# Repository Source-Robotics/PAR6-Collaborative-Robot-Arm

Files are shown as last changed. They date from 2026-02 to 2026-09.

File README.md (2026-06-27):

> [!CAUTION]
> This is a BETA release: Instructions, code, and 3D print files may change in the future and are not yet finalized. If you want to be a part of beta testing check out **this [link!](https://docs.google.com/forms/d/e/1FAIpQLSfJVBVM5K6rCrFRtpijmTBLeePUdGDxUlWBni1VqBrAZwRCwg/viewform
)**

By building and using this system, you acknowledge that it is still under active development and may contain errors, incomplete features, or design issues. You are doing so entirely at your own risk and responsibility.

This project may require troubleshooting, modifications, and technical knowledge. Proceed only if you are comfortable working with electronics, mechanical systems, and software in a development-stage environment.
>

## 🐞 Beta Feedback & Support

Since this project is currently in beta, feedback is highly appreciated.

If you find any mistakes, bugs, or unclear parts, please report them, including issues in:

- Documentation
- BOM and assembly documentation
- Source code
- STL and other 3D print files

Please open an issue, send us a message on Discord, or contact us via email with as much detail as possible so we can fix it quickly.

## 🤝 Contributing

Use GitHub issues to track open work before starting a pull request:

- Open one issue per bug, task, or feature request.
- Keep each pull request focused on one logical change.
- Link the related issue in the pull request description.
- Describe what changed and what you tested.
- For larger changes, open an issue first and agree on the approach before coding.

 ### How you can contribute

Review issues: reproduce bugs reported by others, spot duplicates, improve descriptions, and help users who need support.
Submit fixes: pick an open issue or feature request and submit a pull request with your implementation.
Test pull requests: run proposed changes and report your results — testing on real hardware is invaluable.
Review contributions: help others by reviewing code and suggesting better implementation approaches.
Improve documentation: write new content or polish what's already there.

More details on how to contribute here: https://github.com/Source-Robotics/.github?tab=contributing-ov-file

## 🧩 Open TODOs

Open tasks that contributors can pick up. Before starting work, please open or comment on the related issue so work is not duplicated.

| Area | Task | Status |
| :--- | :--- | :---: |
| Documentation | Typos, readability changes, structure for the .md files| Open |
| Documentation | Finalize BOM,  Fix links, reference images, exact number of parts... | Open |
| Hardware | Create .3mf print files for robot (follow 3D printn table) | Open |
| Hardware | Issues in 3D print / model files. | Open |
| Hardware | Recommendations for easier assembly of the robot | Open |
| Software | TODO | Open |

Status options: `Open`, `In progress`, `Needs review`, `Blocked`, `Done`.

 ### How you can contribute

* Triage issues: reproduce bugs reported by others, spot duplicates, improve descriptions, and help users who need support.
* Submit fixes: pick an open issue or feature request and submit a pull request with your implementation.
* Test pull requests: run proposed changes and report your results — testing on real hardware is invaluable.
* Review contributions: help others by reviewing code and suggesting better implementation approaches.
* Improve documentation: write new content or polish what's already there.

## Related repos
* https://github.com/Source-Robotics/STEPFOC-stepper-controller
* https://github.com/Source-Robotics/RCB-Robot-Control-Box

<div align="center">

# PAR6-Collaborative-Robot-Arm

</div>

---

<p align="center">
  
  
  
  <a href="https://github.com/petercorke/robotics-toolbox-python">Powered by the Robotics Toolbox</a>
  
</p>

<p align="center">
  
  
  
  
  
  
</p>

<div align="center">

3D Printed Collaborative Robot - Open Source Software, Manuals & 3D print files ·

Designed for Embodied/Physical  AI, Safety & Ease of use

</div>

## 💡 News

[2025-04-03] Beta Release! Contributions from the open-source community are highly encouraged, and we welcome feedback and bug reports through the GitHub Issues page.

## 📖 Project Overview

PAR6 is a 3D-printed collaborative robot arm platform designed for research, education, and rapid prototyping in physical AI.

The project combines mechanical design files, assembly documentation, and software resources to support full-stack robotics development.

Key focus areas:

- Embodied AI and physical AI experiments and validation
- Teleoperation workflows and human-in-the-loop control
- Learning from demonstration (LfD) pipelines
- Imitation learning and dataset generation
- VLA-style data collection for AI-native robotics
- Accessible robotics research through open hardware and open documentation

## ⚒️How to build / Where to buy?

**Check video manuals below, Source all the parts from BOM**

**You will also need to build Control box from this repo:**
* https://github.com/Source-Robotics/RCB-Robot-Control-Box

## 📚Documentation:

| Resource | Description |
|---|---|
| [3D Print Files](3D%20Print%20Files/) | Printable STL part files for the PAR6 robot arm,  |
| [BOM](BOM/) | Bill of materials and reference images for sourcing the required parts |
| [Building Instructions](Building%20Instructions/) | Assembly notes, cable building instructions, and supporting datasheets -- **Check Video Manuals below**|
| [PAR6 Description](PAR6%20Description/) |  XML files, and URDF resources for simulation  |

Video Assembly manual
* https://youtu.be/3Rrd6hjBnM4

Cable Assembly:
* https://youtu.be/QlNfWAga1l0
* https://youtu.be/GOb1vQsjfOs

RCB Box:
* https://youtu.be/qAzd839ixuw

## ⚙️ Hardware Specifications

TODO

## 🌐 More about PAR6 robotic arm

| YouTube | Instagram | Twitter | LinkedIn |
|---|---|---|---|
|  |  |  |  |

| Discord | Forum | Hackaday | Blog |
|---|---|---| ---|
|  |  |  |  

## 🛡️ Licensing

**CERN Open Hardware Licence Version 2 - Strongly Reciprocal**

## 💸Support us

The majority of this project is open source and freely available to everyone. Your assistance, whether through donations or advice, is highly valued. Thank you!

 


## 🙌 References & Acknowledgments

## ⚠️ Safety, Liability & Disclaimer
This project includes experimental software, hardware designs, and assembly documentation that are still under development and may contain bugs, errors, or incomplete features. By using, building, or modifying this project, you acknowledge that:

* You use this project entirely at your own risk
* You are solely responsible for safe assembly, testing, and operation
* No guarantee is made regarding correctness, safety, or reliability
* The authors are not responsible for any damage, injury, or loss resulting from the use or misuse of this project
* Hardware performance and safety depend on user assembly, component quality, calibration, and handling, which cannot be guaranteed
* This project is provided “as is.” If you choose to build a device yourself using these files, designs, or instructions, you do so without any warranties or guarantees, including regarding safety, reliability, or suitability for any particular purpose.

THIS PROJECT INVOLVES LETHAL VOLTAGES AND OTHER SERIOUS HAZARDS THAT CAN CAUSE SEVERE INJURY. YOU MUST READ THE FULL [SAFETY WARNING AND DISCLAIMER DOCUMENT](SAFETY_WARNING_AND_DISCLAIMER.md)  BEFORE USING ANY PROJECT FILES. BY PROCEEDING, YOU ACKNOWLEDGE AND ACCEPT ALL RISKS AND AGREE TO USE THIS PROJECT ENTIRELY AT YOUR OWN RESPONSIBILITY.

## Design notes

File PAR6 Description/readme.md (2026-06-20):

# Source Robotics PAR6 Description (MJCF)

> [!IMPORTANT]
> Requires MuJoCo 3.1.3 or later.

## Changelog

See [CHANGELOG.md](./CHANGELOG.md) for a full history of changes.

## ⚒️TODO 

- Add correct joint limits to URDF and MJCF files

## Overview

This package contains a simplified robot description (MJCF) and URDF files of the [PAR6 robotic arm](https://source-robotics.com/) developed by [Source Robotics](https://source-robotics.com/).

There are 2 available MJCF files.

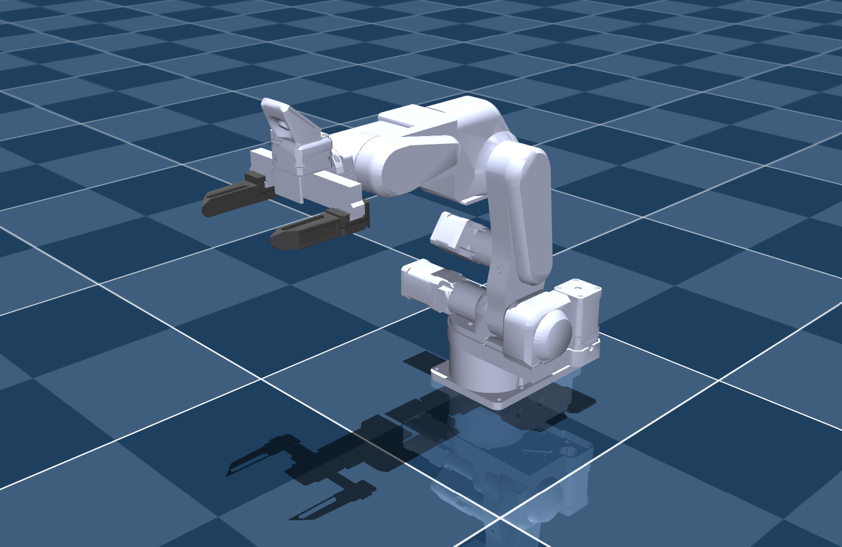
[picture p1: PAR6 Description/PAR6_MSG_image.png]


* PAR6 with MSG gripper

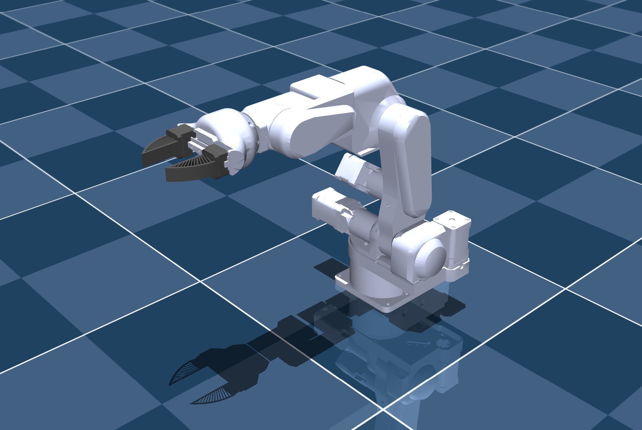
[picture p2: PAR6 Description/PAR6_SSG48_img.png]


* PAR6 with SSG48 gripper

## Online mujoco viewer

https://mujoco-viewer.org/

## URDF folder

[URDF](./URDF/) folder contains 3 different versions:
* PAR6 with flange
* PAR6 with MSG gripper
* PAR6 with SSG48 gripper

More about URDF here: [Link](./urdf.md)

## URDF → MJCF derivation steps

1. Loaded the URDF into MuJoCo and saved a corresponding MJCF.
2. Manually edited the MJCF to extract common properties into the `<default>` section.
3. Added position-controlled actuators for the arm.
4. Added `scene.xml` which includes the robot, with a textured groundplane, skybox, and haze.

## License

This model is released under an [Apache-2.0 License](LICENSE).

## References

Mjcf reference Mujoco managerie
- references: 
- https://mujoco.readthedocs.io/en/stable/XMLreference.html
- https://github.com/google-deepmind/mujoco_menagerie/tree/main/ufactory_lite6
- https://github.com/google-deepmind/mujoco_menagerie/blob/main/trossen_vx300s/vx300s.xml 
- https://github.com/google-deepmind/mujoco_menagerie/blob/main/aloha/aloha.xml
- https://github.com/google-deepmind/mujoco_menagerie/blob/main/franka_emika_panda/panda.xml 
- https://github.com/jeongeun980906/lerobot-mujoco-tutorial/blob/master/asset/robotis_omy/omy.xml

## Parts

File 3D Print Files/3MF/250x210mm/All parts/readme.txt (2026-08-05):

This file contains multiple plates with all the parts. In order to be correctly read, it might be necessary to open it using OrcaSlicer. It is for reference only, as there is both single color and multi colors folders available containing ready to print files.

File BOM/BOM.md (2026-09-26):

# PAR6 – Bill of Materials (BOM)

This BOM lists all components required to build the PAR6 robot arm based on the official kiting list.

> [!NOTE]
> If any product links are broken, unavailable, or no longer point to the correct item, please [open an issue](https://github.com/Source-Robotics/PAR6-Collaborative-Robot-Arm/issues/new), send us a message on Discord, or contact us via email. You can also use the reference images to find the same or an equivalent part from another supplier.

---

## RCB - Robot Control Box

The Robot Control Box is also required for the PAR6 build. Use the separate [RCB Robot Control Box BOM](https://github.com/Source-Robotics/RCB-Robot-Control-Box/blob/main/BOM/BOM.md) for the control box components.

---

## Screws and Nuts

| Diameter / Type | Length | Quantity | Description |
| :--- | :--- | :--- | :--- |
| M4 | 10 mm | 7 | DIN 912 / ISO 4762 (Socket head cap) 
| M3 | 8 mm | 50 | DIN 912 / ISO 4762 (Socket head cap) 
| M3 | 14 mm | 33 | DIN 912 / ISO 4762 (Socket head cap) 
| M3 | 25 mm | 4 | DIN 912 / ISO 4762 (Socket head cap) 
| M2 | 10 mm | 2 | DIN 912 / ISO 4762 (Socket head cap) 
| M2 | 4 mm | 2 | DIN 912 / ISO 4762 (Socket head cap) 
 M3 | 45 mm | 6 | DIN 912 / ISO 4762 (Socket head cap) 
  M3.5 | 14 mm | 8 | **used for shaft couplers!** DIN 912 / ISO 4762 (Socket head cap) 
| M3 | 16 mm | 6 | DIN 912 / ISO 4762 (Socket head cap) 
| M3 | 12 mm | 3 | DIN 912 / ISO 4762 (Socket head cap) 
| M4 | 16 mm | 16 | DIN 912 / ISO 4762 (Socket head cap) 
| M4 | 14 mm | 4 | DIN 912 / ISO 4762 (Socket head cap)
| M4 | 50 mm | 4 | DIN 912 / ISO 4762 (Socket head cap)
| M3 | 15 mm or 16 | 5 | Tapered / Countersunk screw head 
| M5 | 16 mm | 8 | DIN 912 / ISO 4762 (Socket head cap)|
| M3 | 22 mm | 4 | DIN 912 / ISO 4762 (Socket head cap)|
| M3 | 40 mm | 8 | DIN 912 / ISO 4762 (Socket head cap)| 
| M3| 60 mm | 12 | DIN 912 / ISO 4762 (Socket head cap)| 

---

---

## Consumables

| Name | Type | Quantity | Description | Link | 
| :--- | :--- | :--- | :--- | :--- |
| Threadlocker blue | Loctite 243 | 1 | Use for gearbox shaft coupler set screws|  | 
| Threadlocker green| Loctite 648 | 1 | Use for gearbox shaft couplers and shafts |  | 

---

## Gearboxes

> [!NOTE]
>     **Use EG series gearboxes for best perfromance. You can also mix EG and MG series as you wish for robots joints but for 1 robot you will need 1 x 10:1, 1 x 20:1 and 1 x 25:1 of any type either MG or EG**

| Name | Type | Quantity | Description | Link | ALT link| Reference Image |
| :--- | :--- | :--- | :--- | :--- | :--- |:--- |
| Gearbox 20:1 | Nema 17 20:1 | 1 | (Joint 3 gearbox - Elbow) EG Series precision planetary | [Link](https://www.omc-stepperonline.com/eg-series-planetary-gearbox-gear-ratio-20-1-backlash-20-arc-min-for-nema-17-stepper-motor-eg17-g20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) | [Alt Link](https://s.click.aliexpress.com/e/_oEhMNU5) | [Link](BOM%20reference%20images/stepper%2020_1.jpg) |
| Gearbox 10:1 | Nema 17 10:1 | 1 | (Joint 6 gearbox - Wrist 3) EG Series precision planetary | [Link](https://www.omc-stepperonline.com/eg-series-planetary-gearbox-gear-ratio-10-1-backlash-15-arc-min-for-nema-17-stepper-motor-eg17-g10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) | [Alt Link](https://s.click.aliexpress.com/e/_oEhMNU5) |[Link](BOM%20reference%20images/stepper%2010_1.jpg) |
| Gearbox 25:1 | Nema 17 25:1 | 1 | (Joint 1 gearbox - Shoulder) EG Series precision planetary | [Link](https://s.click.aliexpress.com/e/_c3b5S46t) | [Alt Link](https://s.click.aliexpress.com/e/_c2QcIBnD) |[Link](BOM%20reference%20images/stepper%2010_1.jpg) |

> [!NOTE]
>     **You can use Lower quality MSG type reducers. They offer a tradeoff where they are cheaper but have more backlash**

| Name | Type | Quantity | Description | Link | ALT link| Reference Image |
| :--- | :--- | :--- | :--- | :--- | :--- |:--- |
| Gearbox 20:1 | Nema 17 20:1 | 1 | (Joint 3 gearbox - Elbow) MGL Series precision planetary | [Link](https://www.omc-stepperonline.com/mgl-series-planetary-gearbox-gear-ratio-20-1-backlash-45arc-min-for-5mm-shaft-standard-nema-17-stepper-motor-mgl17-g20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) | [Alt Link](https://s.click.aliexpress.com/e/_c3JNRXad) | [Link](BOM%20reference%20images/stepper%2020_1.jpg) |
| Gearbox 10:1 | Nema 17 10:1 | 1 | (Joint 6 gearbox - Wrist 3) MGL Series precision planetary | [Link](https://www.omc-stepperonline.com/mgl-series-planetary-gearbox-gear-ratio-10-1-backlash-30arc-min-for-5mm-shaft-standard-nema-17-stepper-motor-mgl17-g10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) | [Alt Link](https://s.click.aliexpress.com/e/_c3JNRXad) |[Link](BOM%20reference%20images/stepper%2010_1.jpg) |
| Gearbox 25:1 | Nema 17 25:1 | 1 | (Joint 1 gearbox - Shoulder) MGL Series precision planetary | [Link](https://www.omc-stepperonline.com/mgl-series-planetary-gearbox-gear-ratio-25-1-backlash-45arc-min-for-5mm-shaft-standard-nema-17-stepper-motor-mgl17-g25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) | [Alt Link](https://s.click.aliexpress.com/e/_c3JNRXad) |[Link](BOM%20reference%20images/stepper%2010_1.jpg) |

---

## Motors

| Name | Type | Quantity | Description | Link | ALT link| Reference Image |
| :--- | :--- | :--- | :--- | :--- | :--- | :--- |
| Stepper 17HS08-1004S | Nema 17 | 1 | 16Ncm, 42x42x21.5mm; used in J6| [Link](https://www.omc-stepperonline.com/nema-17-bipolar-1-8deg-16ncm-22-6oz-in-1a-3-7v-42x42x20mm-4-wires-17hs08-1004s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) | [Alt Link](https://s.click.aliexpress.com/e/_oo1LTs7) |[Link](BOM%20reference%20images/stepper%2021_5mm.jpg) |
| Stepper 17HS16-2004S1 | Nema 17 | 2 | 45Ncm, 42x42x40mm; used in J5, J4| [Link](https://www.omc-stepperonline.com/nema-17-bipolar-45ncm-64oz-in-2a-42x42x40mm-4-wires-w-1m-cable-connector-17hs16-2004s1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) | [Alt Link](https://s.click.aliexpress.com/e/_oC1Ii0v) |[Link](BOM%20reference%20images/stepper%2040mm.jpg) |
| Stepper 17HS24-2104S | Nema 17 | 3 | 65Ncm, 42x42x60mm; used in J3, J2, J1 | [Link](https://www.omc-stepperonline.com/nema-17-bipolar-1-8deg-65ncm-92oz-in-2-1a-3-36v-42x42x60mm-4-wires-17hs24-2104s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) | [Alt Link](https://s.click.aliexpress.com/e/_opq2ugp) |[Link](BOM%20reference%20images/stepper%2060mm.jpg) |

---

## Belts and Pulleys

| Name | Type | Quantity | Description | Link | ALT link| Reference Image |
| :--- | :--- | :--- | :--- | :--- | :--- | :--- |
| Joint 1 belt | HTD3M 396 | 1 | 6 mm width | [Link](https://s.click.aliexpress.com/e/_c3LnffKl) | |[Link](BOM%20reference%20images/HTD%203M%20belt.png) |
| Joint 3 belt | HTD3M 342 | 1 | 6 mm width | [Link](https://s.click.aliexpress.com/e/_c4O7CHOd) | |[Link](BOM%20reference%20images/HTD%203M%20belt.png) |
| Joint 4 belt | HTD3M 201 | 1 | 6 mm width | [Link](https://s.click.aliexpress.com/e/_c4NiUycd) | |[Link](BOM%20reference%20images/HTD%203M%20belt.png) |
| Joint 5 belt | HTD3M 246 | 1 | 6 mm width | [Link](https://s.click.aliexpress.com/e/_c4DlcQaD) | |[Link](BOM%20reference%20images/HTD%203M%20belt.png) |
| J4/J5 Pulley | HTD3M 12T | 2 | 5mm bore, 10mm width | [Link](https://s.click.aliexpress.com/e/_DBVgkVp) | |[Link](BOM%20reference%20images/HTD%203M%20pulley.png) |
| J1 Pulley | HTD3M 15T | 1 | 5mm bore, 10mm width | [Link](https://s.click.aliexpress.com/e/_DBVgkVp) | |[Link](BOM%20reference%20images/HTD%203M%20pulley.png) |

---

## Shaft couplers

> [!NOTE]
>     **Joints 2 and 3 can use different shaft coupler options. Choose only one J2/J3 option below (quantity 2 total). Option 1 gives the best performance if you use the official shaft coupler or machine an equivalent part from the [custom and machined parts](Custom%20%26%20machined%20parts) files. Option 2 is a friction/tension based coupler. Option 3 uses the same coupler as the gripper/flange, but is more prone to slipping and requires the [alternative upper arm STL files](../3D%20Print%20Files/STL/A4_Upper_arm/Alternative%20files).**

| Option | Name | Type | Quantity | Description | Link | ALT link | Reference Image |
| :--- | :--- | :--- | :--- | :--- | :--- | :--- | :--- |
| Option 1 - Recommended Coming soon! | Shaft coupler | For J2 & J3 | 2 | Official or machined D8 oval flange coupler; best performance. See [custom and machined parts](Custom%20%26%20machined%20parts). | [Link](https://s.click.aliexpress.com/e/_c3UQtavB) | | [Link](BOM%20reference%20images/source_coupler.png) |
| Option 2 | Shaft coupler | For J2 & J3 | 2 | Friction/tension based D8 oval flange coupler; easier to source, but can slip more than Option 1 | [Link](https://s.click.aliexpress.com/e/_c3UQtavB) | | [Link](BOM%20reference%20images/D8_Oval_flange_coupler.png) |
| Option 3 | Shaft coupler | For J2 & J3 | 2 | Gripper/flange style coupler; most prone to slipping and requires the [alternative upper arm STL files](../3D%20Print%20Files/STL/A4_Upper_arm/Alternative%20files) | [Link](https://s.click.aliexpress.com/e/_c2xnQgI7) | | [Link](BOM%20reference%20images/shaft%20coupler%20gripper.png) |
| Required for grippers and flanges | Shaft coupler | For gripper / flange | 1 | M4 screw holes for the end flange or gripper | [Link](https://s.click.aliexpress.com/e/_c2xnQgI7) | | [Link](BOM%20reference%20images/shaft%20coupler%20gripper.png) |

## Bearings and Mechanical Components

| Name | Type | Quantity | Description | Link | ALT link| Reference Image |
| :--- | :--- | :--- | :--- | :--- | :--- | :--- |
| AXK3552 | AXK3552 needle bearing | 1 | 35X52X4, with plates | [Link](https://s.click.aliexpress.com/e/_Dk4bHg7) | |[Link](BOM%20reference%20images/AXK3552%20needle%20bearing.png) |
| NSK HR32906J| NSK HR32906J  Tapered bearing| 5 | Joint 5, 4 and 3 | [Link](https://s.click.aliexpress.com/e/_DcJMtBl) | |[Link](BOM%20reference%20images/Tapered%20bearing.png) |
| NSK HR32907J | NSK HR32907J Tapered bearing | 4 | Joint 1 and 2 | [Link](https://s.click.aliexpress.com/e/_DcJMtBl) | |[Link](BOM%20reference%20images/Tapered%20bearing.png) |
| Tensioning bearing | 3x8x4 | 2 | Ball bearing for belts | [Link](https://s.click.aliexpress.com/e/_DCjfgFV) | |[Link](BOM%20reference%20images/small%20tension%20bearings.png) |
| Tensioning bearing | 3x10x4 | 8 | Ball bearing for belts | [Link](https://s.click.aliexpress.com/e/_DlA33Af) | |[Link](BOM%20reference%20images/small%20tension%20bearings.png) |
 
## Mechanical Components

| Name | Type | Quantity | Description | Link | ALT link| Reference Image |
| :--- | :--- | :--- | :--- | :--- | :--- | :--- |
| Brass inserts |  | 6 | M3, 5mm len, 4.5 OD, used for Flange| [Link](https://s.click.aliexpress.com/e/_c2RX6lzp) | |[Link](BOM%20reference%20images/brass_insert.png) |

---

## PCBs

| Component | Type | Quantity | Description | Link | ALT link| Reference Image |
| :--- | :--- | :--- | :--- | :--- | :--- | :--- |
| Closed loop Stepper Drivers | STEPFOC | 6 | Stepper Drivers | [Link](https://source-robotics.com/products/stepfoc-stepper-controller) | |[Link](BOM%20reference%20images/STEPFOC%20stepper%20driver.png) |
| Gripper connector PCB |  | 1 | Source Robotics website only for beta for now | [Link](TODO) | |[Link](BOM%20reference%20images/Gripper%20connector%20PCB.jpg) |
| Hall sensor PCB |  | 1 | Source Robotics website only for beta for now | [Link](TODO) | |[Link](BOM%20reference%20images/Hall%20sensor%20PCB.jpg) |
| Base Distribution PCB |  | 1 |Source Robotics website only for beta for now | [Link](TODO) | |[Link](BOM%20reference%20images/Base%20Distribution%20board.jpg) |

## Electronics

| Component | Type | Quantity | Description | Link | ALT link| Reference Image |
| :--- | :--- | :--- | :--- | :--- | :--- | :--- |
| Motor controller Magnets | Diametrically Magnetised Magnets | 6 | Stepper Drivers encoder magnets | [Link](https://source-robotics.com/products/6x2-5mm-diametrical-neodymium-magnet) | |[Link](BOM%20reference%20images/Magnet.png) |
| Gripper Magnet | Axial Magnetised Magnets (Regular magnet) | 1 |  |  [Link](https://s.click.aliexpress.com/e/_c4tF3Rzf)  | |[Link](BOM%20reference%20images/Magnet.png) |
| Thermistor  | Thermistor NTC 100K 3950 | 6 | | [Link](https://source-robotics.com/products/100k-ntc-thermistor) | |[Link](BOM%20reference%20images/Thermistor.png) |
| Robot base connector | GX16 4PIN male connector | 1 | Male + Female pair (female part is used in cable making) | [Link](https://s.click.aliexpress.com/e/_c3o4afqR) | |[Link](BOM%20reference%20images/GX16.jpg) |
| E-stop | 19mm | 1 | Emergency switch | [Link](https://s.click.aliexpress.com/e/_c3TdMLgT) | |[Link](BOM%20reference%20images/19mm%20ESTOP.png) |
| Connectors JST ZH 1.5MM 2PIN male  |  | 10 | Used to make custom cables | [Link](https://s.click.aliexpress.com/e/_c37crJFp) | |[Link](BOM%20reference%20images/Connectors%20JST%20ZH.png) |
| Connectors JST XH 2.54MM 2PIN male |  | 10 | Used to make custom cables | [Link](https://s.click.aliexpress.com/e/_c2xeSW0J) | |[Link](BOM%20reference%20images/Connectors%20JST%20XH.jpg) |
| Thermal cement |  | 1 | Used to attach thermistor to stepper motor | [Link](https://s.click.aliexpress.com/e/_c3t5DkcN) | |[Link](BOM%20reference%20images/Thermal%20cement.jpg) |

---

## Wires / Cables

> [!IMPORTANT]
>     **If you dont want to build the wires yourself you can get the wire pack from our store (Coming soon)**

> [!NOTE]
>     **With wires make sure you follow [proper orientation](BOM%20reference%20images/ZH_XH_cable_direction.png) of the connector heads when ordering!**

| Name | Type | Quantity | Description | Link | ALT link| Reference Image |
| :--- | :--- | :--- | :--- | :--- | :--- | :--- |
| JST ZH 1.5MM 2PIN female-female 20-30cm |  | 3 | J5 motor - J6 motor, Gripper connector PCB - J4 wire, J4 motor - Extension wire J6,5,4  | [Link](https://s.click.aliexpress.com/e/_c4CyWKe1) | |[Link](BOM%20reference%20images/ZH_XH_cable_direction.png) |
| JST XH 2.54MM 2PIN female-female 20-30cm |  | 3| J5 motor - J6 motor, Gripper connector PCB - J4 wire, J4 motor - Extension wire J6,5,4  | [Link](https://s.click.aliexpress.com/e/_c4CyWKe1) | |[Link](BOM%20reference%20images/ZH_XH_cable_direction.png) |
| JST ZH 1.5MM 2PIN female-male 23cm | Extension wire (best to build your own)  | 2 | J5 motor - J6 motor,  J4 wire - J4 motor  | [Link]() | |[Link](BOM%20reference%20images/ZH_series_extension_cable.png) |
| JST XH 2.54MM 2PIN female-male 23cm | Extension wire (best to build your own)  |2 | J5 motor - J6 motor,  J4 wire - J4 motor  | [Link]() | |[Link](BOM%20reference%20images/XH_series_extension_cable.png) |
| JST ZH 1.5MM 2PIN female-female 10cm |  | 1 | J5 motor - Gripper connector PCB  | [Link](https://s.click.aliexpress.com/e/_c4CyWKe1) | |[Link](BOM%20reference%20images/ZH_XH_cable_direction.png) |
| JST XH 2.54MM 2PIN female-female 10cm |  |1 | J5 motor - Gripper connector PCB  | [Link](https://s.click.aliexpress.com/e/_c4CyWKe1) | |[Link](BOM%20reference%20images/ZH_XH_cable_direction.png) |
| JST ZH 1.5MM 2PIN male-bare wire 50cm | Best to build your own by extending the linked wires | 1 | Extension wire J6,5,4 -  Base Distribution PCB | [Link](https://s.click.aliexpress.com/e/_c4CyWKe1) | |[Link](BOM%20reference%20images/barewire4.png) | 
| JST XH 2.54MM 2PIN male-bare wire 50cm | Best to build your own by extending the linked wires | 1| Extension wire J6,5,4 -  Base Distribution PCB  | [Link](https://s.click.aliexpress.com/e/_c4CyWKe1) | |[Link](BOM%20reference%20images/barewire1.png) |
| JST ZH 1.5MM 2PIN female-bare wire 50cm | Best to build your own by extending the linked wires | 3 | J3 motor -  Base Distribution PCB, J2 motor -  Base Distribution PCB, J1 motor -  Base Distribution PCB| [Link](https://s.click.aliexpress.com/e/_c4CyWKe1) | |[Link](BOM%20reference%20images/barewire3.png) |
| JST XH 2.54MM 2PIN female-bare wire 50cm |Best to build your own by extending the linked wires  | 3| J3 motor -  Base Distribution PCB, J2 motor -  Base Distribution PCB, J1 motor -  Base Distribution PCB | [Link](https://s.click.aliexpress.com/e/_c4CyWKe1) | |[Link](BOM%20reference%20images/barewire2.png) |
| 18AWG wire 4 colors |  4 wires of 10cm|  |  GX16 connector -  Base Distribution PCB | [Link](https://s.click.aliexpress.com/e/_c3gZPIyV) | |[Link]() |
| Thin wire 3 colors 20 cm AWG 30 - 35|  | | Hall sensor PCB - J6 motor  | [Link](https://s.click.aliexpress.com/e/_c2v3zfdb) | |[Link]() |
| Wire 2 colors for XH extensions | 22 or 24 AWG | 5m black + 5m red | Extending XH power cables and building the bare wire cables above | | | |
| Wire 2 colors for ZH extensions | 28 AWG | 5m black + 5m red | Extending ZH CAN cables and building the bare wire cables above | | | |

---

> [!IMPORTANT]
>     **Cable building guide is [here](../Assembly%20manual/Building_cables.md)**

> [!IMPORTANT]
>     **If you dont want to build the cables yourself you can get the cable pack from our store (Coming soon)**

---

## Electric Gripper options

Default end effector is basic flange. That part can be used to attach any other custom grippers.

Officially supported open-source grippers are:

| Name | Type | Link to buy | Link to build |
| :--- | :--- | :--- | :--- |
MSG compliant AI gripper | Electric - CAN bus comms|  [Link](https://source-robotics.com/products/msg-gripper)  | [Link](https://github.com/Source-Robotics/MSG-compliant-AI-stepper-gripper)  |
SSG48 compliant gripper | Electric - CAN bus comms|  [Link](https://source-robotics.com/products/compliant-gripper) | [Link](https://github.com/Source-Robotics/SSG-48-adaptive-electric-gripper)  |

> [!NOTE]
>     **MSG gripper come in different grip and torque sizes!**

---

## MSG & SSG48 gripper cable

Buy Official cables from Source Robotics: [Link](TODO)

Parts needed if DIY your own cable:

| Type | Length / Spec | Quantity | Description | Link |
|---|---|---|---|---|
| 26 AWG cable | 0.15 mm², 4-wire twisted pair | 0.4 m | ~40 cm usually sufficient | [Link](https://s.click.aliexpress.com/e/_c4m3ggwn) |
| M8 4-pin male wire connector | — | 1 | [See reference image](../BOM/BOM%20reference%20images/M8%20male.png) |[Link](https://s.click.aliexpress.com/e/_c4OWHPKF) |
| M8 4-pin female wire connector | — | 1 | [See reference image](../BOM/BOM%20reference%20images/M8_female.png) | [Link](https://s.click.aliexpress.com/e/_c4OWHPKF) |

> [!NOTE]
>     **PAROL6 and PAR6 use different cables for SSG48 and MSG grippers. Using incorrect one can damage your robot**

## Pneumatics (optional)

> [!NOTE]
>     **These are the items we recommend if you are going to use Pneumatics with PAR6.**

| Name | Type | Quantity | Description | Link | ALT link| Reference Image |
| :--- | :--- | :--- | :--- | :--- | :--- | :--- |
| MHZ2-16D gripper | 4mm PM | 1 | Robot side connector | [Link](https://s.click.aliexpress.com/e/_DD83OLZ) |
| Pneumatic Tube |  | 4x2.5mm | Polyurethane tube | [Link](https://s.click.aliexpress.com/e/_DEhvFyJ) |
| Solenoid valve | 4mm tube connectors, 5/2, 24V | 1 | Polyurethane tube | [Link](https://s.click.aliexpress.com/e/_DDrw0Ux) |

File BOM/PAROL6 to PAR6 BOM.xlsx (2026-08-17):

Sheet: Comparison
PAROL6 vs PAR6 (arm + RCB) - part by part
PAROL6 quantities are as listed in its BOM (screws, bearings and similar are pack sizes). PAR6 quantities are arm + RCB needs combined; rows marked (RCB) are control box parts.
Part | PAROL6 qty | PAR6 qty | Status | Note
MOTORS

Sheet: PAROL6 BOM
PAROL6 - Bill of Materials
Source, fetched 2026-08-17: | https://github.com/PCrnjak/PAROL6-Desktop-robot-arm/blob/main/BOM/BOM.md
Screws and Nuts
Diameter / Type | Length | Quantity | Description
M4 | 10 mm | 20 | DIN 912 / ISO 4762 (hexagon socket head cap)
M3 | 8 mm | 10 | 2 mm head height
M3 | 8 mm | 50 | DIN 912 / ISO 4762 (hexagon socket head cap)
M3 | 14 mm | 30 | DIN 912 / ISO 4762 (hexagon socket head cap)
M3 nut | - | 10 | DIN 912 / ISO 4762 (hexagon socket head cap)
M3 | 25 mm | 10 | DIN 912 / ISO 4762 (hexagon socket head cap)
M2 | 10 mm | 10 | DIN 912 / ISO 4762 (hexagon socket head cap)
M3 | 16 mm | 10 | DIN 912 / ISO 4762 (hexagon socket head cap)
M3 | 6 mm | 10 | Pan head phillips
M3 | 12 mm | 30 | DIN 912 / ISO 4762 (hexagon socket head cap)
M3 | 35 mm | 10 | DIN 912 / ISO 4762 (hexagon socket head cap)
M4 | 16 mm | 30 | DIN 912 / ISO 4762 (hexagon socket head cap)
M4 | 14 mm | 10 | DIN 912 / ISO 4762 (hexagon socket head cap)
M4 | 50 mm | 10 | DIN 912 / ISO 4762 (hexagon socket head cap)
M3 | 15 mm | 2 | Tapered screw head
Gearboxes
For cheaper gearbox options you can use MG series planetary gearboxes. They have bigger backlash but are cheaper. Link - Aliexpress Link (https://www.omc-stepperonline.com/mg-series-planetary-gearbox)
Name | Type | Quantity | Description | Link | ALT link | Reference Image
Gearbox 20:1 | Nema 17 20:1 | 2 | EG precision planetary | Link (https://www.omc-stepperonline.com/eg-series-planetary-gearbox-gear-ratio-20-1-backlash-20-arc-min-for-nema-17-stepper-motor-eg17-g20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) | Link (https://s.click.aliexpress.com/e/_oEhMNU5) | Link (https://github.com/PCrnjak/PAROL6-Desktop-robot-arm/blob/main/BOM/BOM%20reference%20images/stepper%2020_1.jpg)
Gearbox 10:1 | Nema 17 10:1 | 1 | EG precision planetary | Link (https://www.omc-stepperonline.com/eg-series-planetary-gearbox-gear-ratio-10-1-backlash-15-arc-min-for-nema-17-stepper-motor-eg17-g10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) | Link (https://s.click.aliexpress.com/e/_oEhMNU5) | Link (https://github.com/PCrnjak/PAROL6-Desktop-robot-arm/blob/main/BOM/BOM%20reference%20images/stepper%2010_1.jpg)
Motors
Name | Type | Quantity | Description | Link | ALT link | Reference Image
Stepper 1 | Nema 17 | 1 | 16Ncm, 42x42x20mm | Link (https://www.omc-stepperonline.com/nema-17-bipolar-1-8deg-16ncm-22-6oz-in-1a-3-7v-42x42x20mm-4-wires-17hs08-1004s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) | Link (https://s.click.aliexpress.com/e/_oo1LTs7) | Link (https://github.com/PCrnjak/PAROL6-Desktop-robot-arm/blob/main/BOM/BOM%20reference%20images/stepper%2021_5mm.jpg)
Stepper 2 | Nema 17 | 3 | 45Ncm, 42x42x40mm | Link (https://www.omc-stepperonline.com/nema-17-bipolar-45ncm-64oz-in-2a-42x42x40mm-4-wires-w-1m-cable-connector-17hs16-2004s1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) | Link (https://s.click.aliexpress.com/e/_oC1Ii0v) | Link (https://github.com/PCrnjak/PAROL6-Desktop-robot-arm/blob/main/BOM/BOM%20reference%20images/stepper%2040mm.jpg)
Stepper 3 | Nema 17 | 2 | 65Ncm, 42x42x60mm | Link (https://www.omc-stepperonline.com/nema-17-bipolar-1-8deg-65ncm-92oz-in-2-1a-3-36v-42x42x60mm-4-wires-17hs24-2104s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) | Link (https://s.click.aliexpress.com/e/_opq2ugp) | Link (https://github.com/PCrnjak/PAROL6-Desktop-robot-arm/blob/main/BOM/BOM%20reference%20images/stepper%2060mm.jpg)
Belts
Name | Type | Quantity | Description | Link | ALT link | Reference Image
Joint 1 belt | HTD3 396 | 1 | 6 mm width | Link (https://s.click.aliexpress.com/e/_c3LnffKl) |  | Link (https://github.com/PCrnjak/PAROL6-Desktop-robot-arm/blob/main/BOM/BOM%20reference%20images/HTD%203M%20belt.png)
Joint 3 belt | HTD3 342 | 1 | 6 mm width | Link (https://s.click.aliexpress.com/e/_c4O7CHOd) |  | Link (https://github.com/PCrnjak/PAROL6-Desktop-robot-arm/blob/main/BOM/BOM%20reference%20images/HTD%203M%20belt.png)
Joint 4 belt | HTD3 201 | 1 | 6 mm width | Link (https://s.click.aliexpress.com/e/_c4NiUycd) |  | Link (https://github.com/PCrnjak/PAROL6-Desktop-robot-arm/blob/main/BOM/BOM%20reference%20images/HTD%203M%20belt.png)
Joint 5 belt | HTD3 246 | 1 | 6 mm width | Link (https://s.click.aliexpress.com/e/_c4DlcQaD) |  | Link (https://github.com/PCrnjak/PAROL6-Desktop-robot-arm/blob/main/BOM/BOM%20reference%20images/HTD%203M%20belt.png)
Pulleys
Name | Type | Quantity | Description | Link | ALT link | Reference Image
J4 pulley, J5 pulley | HTD3M 12 tooth | 2 | 5mm bore, 10mm width | Link (https://s.click.aliexpress.com/e/_DFYERWX) |  | Link (https://github.com/PCrnjak/PAROL6-Desktop-robot-arm/blob/main/BOM/BOM%20reference%20images/HTD%203M%20pulley.png)
J1 pulley | HTD3M 15 tooth | 1 | 5mm bore, 10mm width | Link (https://s.click.aliexpress.com/e/_DBVgkVp) |  | Link (https://github.com/PCrnjak/PAROL6-Desktop-robot-arm/blob/main/BOM/BOM%20reference%20images/HTD%203M%20pulley.png)
Shaft couplers
Name | Type | Quantity | Description | Link | ALT link | Reference Image
Shaft coupler | Shaft coupler | 3 | 8 mm hole shaft, M4 screw holes | Link (https://s.click.aliexpress.com/e/_c2xnQgI7) |  | Link (https://github.com/PCrnjak/PAROL6-Desktop-robot-arm/blob/main/BOM/BOM%20reference%20images/shaft%20coupler%20gripper.png)
Bearings
Name | Type | Quantity | Description | Link | ALT link | Reference Image
Bearing 1 | AXK3552 | 1 | 35X52X4, needs to have top and bottom plate | Link (https://s.click.aliexpress.com/e/_Dk4bHg7) |  | Link (https://github.com/PCrnjak/PAROL6-Desktop-robot-arm/blob/main/BOM/BOM%20reference%20images/AXK3552%20needle%20bearing.png)
Bearing 2 | NSK HR32906J | 5 | Joint 5, 4 and 3 | Link (https://s.click.aliexpress.com/e/_DcJMtBl) |  | Link (https://github.com/PCrnjak/PAROL6-Desktop-robot-arm/blob/main/BOM/BOM%20reference%20images/Tapered%20bearing.png)
Bearing 3 | NSK HR32907J | 4 | Joint 1 and 2 | Link (https://s.click.aliexpress.com/e/_DcJMtBl) |  | Link (https://github.com/PCrnjak/PAROL6-Desktop-robot-arm/blob/main/BOM/BOM%20reference%20images/Tapered%20bearing.png)
Tension bearing | Ball bearing 3x8x4 | 20 | Used for belt tension | Link (https://s.click.aliexpress.com/e/_DCjfgFV) |  | Link (https://github.com/PCrnjak/PAROL6-Desktop-robot-arm/blob/main/BOM/BOM%20reference%20images/small%20tension%20bearings.png)
Tension bearing | Ball bearing 3x10x4 | 20 | Used for belt tension | Link (https://s.click.aliexpress.com/e/_DlA33Af) |  | Link (https://github.com/PCrnjak/PAROL6-Desktop-robot-arm/blob/main/BOM/BOM%20reference%20images/small%20tension%20bearings.png)
Electronics
Name | Type | Quantity | Description | Link | ALT link | Reference Image
PAROL control board |  | 1 | source-robotics.com | Link (https://source-robotics.com/products/parol6-control-board)
TMC5160 |  | 6 | Drivers from the links are tested. Use any other at own risk | Link (https://s.click.aliexpress.com/e/_c3Jc52V9) | Link (https://s.click.aliexpress.com/e/_Dd8Cjkb)
Thermal paste / cement |  | 2 | Needed only if your control board has no drivers! | Link (https://s.click.aliexpress.com/e/_c2u86OEn) |  | Link (https://github.com/PCrnjak/PAROL6-Desktop-robot-arm/blob/main/BOM/BOM%20reference%20images/Thermal%20cement.jpg)
On/Off button |  | 1 | 12mm 3-6V | Link (https://s.click.aliexpress.com/e/_DBpZV3h) |  | Link (https://github.com/PCrnjak/PAROL6-Desktop-robot-arm/blob/main/BOM/BOM%20reference%20images/button.png)
JST PH 2.0mm 200mm 4PIN |  | 1 | For power button | Link (https://s.click.aliexpress.com/e/_DeObQ1D) |  | Link (https://github.com/PCrnjak/PAROL6-Desktop-robot-arm/blob/main/BOM/BOM%20reference%20images/JST_PH.png)
Noctua NF-A4x20 5V 40mm |  | 1 | or any 40mm 5V fan
Power connector - male + female |  | 1 | GX16 2PIN | Link (https://s.click.aliexpress.com/e/_DcHjMfN) |  | Link (https://github.com/PCrnjak/PAROL6-Desktop-robot-arm/blob/main/BOM/BOM%20reference%20images/GX16.jpg)
Gripper connector (electric) |  | 1 | M8 sensor Female 4 pin | Link (https://s.click.aliexpress.com/e/_DDQz9iP) |  | Link (https://github.com/PCrnjak/PAROL6-Desktop-robot-arm/blob/main/BOM/BOM%20reference%20images/M8%20connector%20female%204pin.png)
Power supply |  | 1 | Any 24V 5A supply | Link (https://www.omc-stepperonline.com/edr-120-24-mean-well-120w-24vdc-5a-115-230vac-din-rail-power-supply-edr-120-24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) | Link (https://s.click.aliexpress.com/e/_olFOM5Z)
Limit switches |  | 3 | Type ZW12-3 | Link (https://s.click.aliexpress.com/e/_DBq6eeF) |  | Link (https://github.com/PCrnjak/PAROL6-Desktop-robot-arm/blob/main/BOM/BOM%20reference%20images/LIMIT_SWITCH.png)
Inductive sensor 1 |  | 1 | 4mm NPN NO | Link (https://s.click.aliexpress.com/e/_c40MRkk5) | Link (https://s.click.aliexpress.com/e/_c3CMbO1h) | Link (https://github.com/PCrnjak/PAROL6-Desktop-robot-arm/blob/main/BOM/BOM%20reference%20images/INDUCTIVE_4MM.png)
Inductive sensor 2 |  | 1 | GX-F8A | Link (https://s.click.aliexpress.com/e/_c4VxLtW3) |  | Link (https://github.com/PCrnjak/PAROL6-Desktop-robot-arm/blob/main/BOM/BOM%20reference%20images/GX-F8A.png)
Inductive sensor 3 |  | 1 | M5, NPN NO | Link (https://s.click.aliexpress.com/e/_c3zGvxrP) | Link (https://s.click.aliexpress.com/e/_c3CMbO1h) | Link (https://github.com/PCrnjak/PAROL6-Desktop-robot-arm/blob/main/BOM/BOM%20reference%20images/INDUCTIVE_5MM.png)
Estop |  | 1 | Any NC estop | Link (https://s.click.aliexpress.com/e/_c3Bn4RR5) |  | Link (https://github.com/PCrnjak/PAROL6-Desktop-robot-arm/blob/main/BOM/BOM%20reference%20images/19mm%20ESTOP.png)
Cable gland for estop |  | 1 | PG7 type | Link (https://s.click.aliexpress.com/e/_DdJj62p) |  | Link (https://github.com/PCrnjak/PAROL6-Desktop-robot-arm/blob/main/BOM/BOM%20reference%20images/CABLE_GLAND.png)
M3 brass insert |  | 4 | M3, 6mm lenght | Link (https://s.click.aliexpress.com/e/_DmZR9AN) |  | Link (https://github.com/PCrnjak/PAROL6-Desktop-robot-arm/blob/main/BOM/BOM%20reference%20images/brass_insert.png)
Pneumatic connector - robot |  | 4 | 4 mm type PM | Link (https://s.click.aliexpress.com/e/_c3GpN5cR) |  | Link (https://github.com/PCrnjak/PAROL6-Desktop-robot-arm/blob/main/BOM/BOM%20reference%20images/PM4.png)
Pneumatic Gripper |  | 1 | MHZ2-16D | Link (https://s.click.aliexpress.com/e/_c4EJl0Qr) |  | Link (https://github.com/PCrnjak/PAROL6-Desktop-robot-arm/blob/main/BOM/BOM%20reference%20images/MHZ.png)
Pneumatic gripper connector |  | 2 | PC4 - M5 | Link (https://s.click.aliexpress.com/e/_DkCJqUL) |  | Link (https://github.com/PCrnjak/PAROL6-Desktop-robot-arm/blob/main/BOM/BOM%20reference%20images/PC4-M5.png)
Pneumatic tube |  | 5 meters | 1 meter, 4x2.5mm | Link (https://s.click.aliexpress.com/e/_DEhvFyJ) |  | Link (https://github.com/PCrnjak/PAROL6-Desktop-robot-arm/blob/main/BOM/BOM%20reference%20images/Pneumatic_tube.png)
xt30 connector female |  | 1 | Used to deliver power to PAROL6 PCB | Link (https://s.click.aliexpress.com/e/_DllR7eL)
Stlink / programming adapter |  | 1 | Use our Official programming adapter for ease of use! Pin order needs to be: SWCLK, SWDIO, GND, 3V3, 5V (https://source-robotics.com/products/parol6-programming-adapter) | Link (https://s.click.aliexpress.com/e/_DCPwBnn)
USB B cable |  | 1 | Comms to the PC
5/2 solenoid air valve |  | 1 | 4mm tube connectors, 5/2, 24V | Link (https://s.click.aliexpress.com/e/_DDrw0Ux) |  | Link (https://github.com/PCrnjak/PAROL6-Desktop-robot-arm/blob/main/BOM/BOM%20reference%20images/solenoid_valve.png)
Vacuum gripper
Name | Type | Quantity | Description | Link | ALT link | Reference Image
Suction cup gripper |  | 1 |  | Link (https://www.aliexpress.com/item/4000538850003.html)
Vacuum generator |  | 1 |  | Link (https://s.click.aliexpress.com/e/_DdTAyOZ)
4mm to 6mm coupler |  | 1 |  | Link (https://s.click.aliexpress.com/e/_DeEEqHR)
Small print bed modification
These parts are only needed if your printer bed is too small for `J1_turret_rework_blocker` and `Upper_arm`. Both parts are split in two and joined with dowel pins and epoxy after printing. STL files are in STL/SMALL_PRINT_BED. Nothing else in the build changes. (https://github.com/PCrnjak/PAROL6-Desktop-robot-arm/blob/main/BOM/../STL/SMALL_PRINT_BED)
Name | Type | Quantity | Description | Link | ALT link | Reference Image
J1 turret dowel pin | Dowel pin 4 x 18 mm | 3 | Solid cylindrical, stainless or hardened steel | Link (https://www.aliexpress.com/item/1005009401701158.html)
Upper arm dowel pin | Dowel pin 6 x 22 mm | 4 | Solid cylindrical, stainless or hardened steel | Link (https://www.aliexpress.com/item/1005009401701158.html)
Two part epoxy | Epoxy adhesive | 1 | 1:1 mix, slow setting | Link (https://www.aliexpress.com/item/1005012397836514.html)

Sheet: PAR6 Arm BOM
PAR6 arm - Bill of Materials
Source, fetched 2026-08-17: | https://github.com/Source-Robotics/PAR6-Collaborative-Robot-Arm/blob/main/BOM/BOM.md
The RCB Robot Control Box is also required for the PAR6 build. See the RCB BOM sheet.
Screws and Nuts
Diameter / Type | Length | Quantity | Description
M4 | 10 mm | 7 | DIN 912 / ISO 4762 (Socket head cap)
M3 | 8 mm | 50 | DIN 912 / ISO 4762 (Socket head cap)
M3 | 14 mm | 33 | DIN 912 / ISO 4762 (Socket head cap)
M3 | 25 mm | 4 | DIN 912 / ISO 4762 (Socket head cap)
M2 | 10 mm | 2 | DIN 912 / ISO 4762 (Socket head cap)
M2 | 4 mm | 2 | DIN 912 / ISO 4762 (Socket head cap)
M3 | 16 mm | 6 | DIN 912 / ISO 4762 (Socket head cap)
M3 | 12 mm | 3 | DIN 912 / ISO 4762 (Socket head cap)
M4 | 16 mm | 16 | DIN 912 / ISO 4762 (Socket head cap)
M4 | 14 mm | 4 | DIN 912 / ISO 4762 (Socket head cap)
M4 | 50 mm | 4 | DIN 912 / ISO 4762 (Socket head cap)
M3 | 15 mm or 16 | 5 | Tapered / Countersunk screw head
M5 | 16 mm | 8 | DIN 912 / ISO 4762 (Socket head cap)
M3 | 22 mm | 4 | DIN 912 / ISO 4762 (Socket head cap)
M3 | 40 mm | 8 | DIN 912 / ISO 4762 (Socket head cap)
M3 | 60 mm | 12 | DIN 912 / ISO 4762 (Socket head cap)
Consumables
Name | Type | Quantity | Description | Link
Threadlocker blue | Loctite 243 | 1 | Use for gearbox shaft coupler set screws
Threadlocker green | Loctite 648 | 1 | Use for gearbox shaft couplers and shafts
Gearboxes
**Use EG series gearboxes for best perfromance. You can also mix EG and MG series as you wish for robots joints but for 1 robot you will need 1 x 10:1, 1 x 20:1 and 1 x 25:1 of any type either MG or EG**
**You can use Lower quality MSG type reducers. They offer a tradeoff where they are cheaper but have more backlash**
Name | Type | Quantity | Description | Link | ALT link | Reference Image
Gearbox 20:1 | Nema 17 20:1 | 1 | EG Series precision planetary | Link (https://www.omc-stepperonline.com/eg-series-planetary-gearbox-gear-ratio-20-1-backlash-20-arc-min-for-nema-17-stepper-motor-eg17-g20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) | Link (https://s.click.aliexpress.com/e/_oEhMNU5) | Link (https://github.com/Source-Robotics/PAR6-Collaborative-Robot-Arm/blob/main/BOM/BOM%20reference%20images/stepper%2020_1.jpg)
Gearbox 10:1 | Nema 17 10:1 | 1 | EG Series precision planetary | Link (https://www.omc-stepperonline.com/eg-series-planetary-gearbox-gear-ratio-10-1-backlash-15-arc-min-for-nema-17-stepper-motor-eg17-g10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) | Link (https://s.click.aliexpress.com/e/_oEhMNU5) | Link (https://github.com/Source-Robotics/PAR6-Collaborative-Robot-Arm/blob/main/BOM/BOM%20reference%20images/stepper%2010_1.jpg)
Gearbox 25:1 | Nema 17 25:1 | 1 | EG Series precision planetary | Link (https://s.click.aliexpress.com/e/_c3b5S46t) | Link (https://s.click.aliexpress.com/e/_c2QcIBnD) | Link (https://github.com/Source-Robotics/PAR6-Collaborative-Robot-Arm/blob/main/BOM/BOM%20reference%20images/stepper%2010_1.jpg)
Name | Type | Quantity | Description | Link | ALT link | Reference Image
Gearbox 20:1 | Nema 17 20:1 | 1 | MGL Series precision planetary | Link (https://www.omc-stepperonline.com/mgl-series-planetary-gearbox-gear-ratio-20-1-backlash-45arc-min-for-5mm-shaft-standard-nema-17-stepper-motor-mgl17-g20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) | Link (https://s.click.aliexpress.com/e/_c3JNRXad) | Link (https://github.com/Source-Robotics/PAR6-Collaborative-Robot-Arm/blob/main/BOM/BOM%20reference%20images/stepper%2020_1.jpg)
Gearbox 10:1 | Nema 17 10:1 | 1 | MGL Series precision planetary | Link (https://www.omc-stepperonline.com/mgl-series-planetary-gearbox-gear-ratio-10-1-backlash-30arc-min-for-5mm-shaft-standard-nema-17-stepper-motor-mgl17-g10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) | Link (https://s.click.aliexpress.com/e/_c3JNRXad) | Link (https://github.com/Source-Robotics/PAR6-Collaborative-Robot-Arm/blob/main/BOM/BOM%20reference%20images/stepper%2010_1.jpg)
Gearbox 25:1 | Nema 17 25:1 | 1 | MGL Series precision planetary | Link (https://www.omc-stepperonline.com/mgl-series-planetary-gearbox-gear-ratio-25-1-backlash-45arc-min-for-5mm-shaft-standard-nema-17-stepper-motor-mgl17-g25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) | Link (https://s.click.aliexpress.com/e/_c3JNRXad) | Link (https://github.com/Source-Robotics/PAR6-Collaborative-Robot-Arm/blob/main/BOM/BOM%20reference%20images/stepper%2010_1.jpg)
Motors
Name | Type | Quantity | Description | Link | ALT link | Reference Image
Stepper 17HS08-1004S | Nema 17 | 1 | 16Ncm, 42x42x21.5mm; used in J6 | Link (https://www.omc-stepperonline.com/nema-17-bipolar-1-8deg-16ncm-22-6oz-in-1a-3-7v-42x42x20mm-4-wires-17hs08-1004s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) | Link (https://s.click.aliexpress.com/e/_oo1LTs7) | Link (https://github.com/Source-Robotics/PAR6-Collaborative-Robot-Arm/blob/main/BOM/BOM%20reference%20images/stepper%2021_5mm.jpg)
Stepper 17HS16-2004S1 | Nema 17 | 2 | 45Ncm, 42x42x40mm; used in J5, J4 | Link (https://www.omc-stepperonline.com/nema-17-bipolar-45ncm-64oz-in-2a-42x42x40mm-4-wires-w-1m-cable-connector-17hs16-2004s1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) | Link (https://s.click.aliexpress.com/e/_oC1Ii0v) | Link (https://github.com/Source-Robotics/PAR6-Collaborative-Robot-Arm/blob/main/BOM/BOM%20reference%20images/stepper%2040mm.jpg)
Stepper 17HS24-2104S | Nema 17 | 3 | 65Ncm, 42x42x60mm; used in J3, J2, J1 | Link (https://www.omc-stepperonline.com/nema-17-bipolar-1-8deg-65ncm-92oz-in-2-1a-3-36v-42x42x60mm-4-wires-17hs24-2104s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) | Link (https://s.click.aliexpress.com/e/_opq2ugp) | Link (https://github.com/Source-Robotics/PAR6-Collaborative-Robot-Arm/blob/main/BOM/BOM%20reference%20images/stepper%2060mm.jpg)
Belts and Pulleys
Name | Type | Quantity | Description | Link | ALT link | Reference Image
Joint 1 belt | HTD3M 396 | 1 | 6 mm width | Link (https://s.click.aliexpress.com/e/_c3LnffKl) |  | Link (https://github.com/Source-Robotics/PAR6-Collaborative-Robot-Arm/blob/main/BOM/BOM%20reference%20images/HTD%203M%20belt.png)
Joint 3 belt | HTD3M 342 | 1 | 6 mm width | Link (https://s.click.aliexpress.com/e/_c4O7CHOd) |  | Link (https://github.com/Source-Robotics/PAR6-Collaborative-Robot-Arm/blob/main/BOM/BOM%20reference%20images/HTD%203M%20belt.png)
Joint 4 belt | HTD3M 201 | 1 | 6 mm width | Link (https://s.click.aliexpress.com/e/_c4NiUycd) |  | Link (https://github.com/Source-Robotics/PAR6-Collaborative-Robot-Arm/blob/main/BOM/BOM%20reference%20images/HTD%203M%20belt.png)
Joint 5 belt | HTD3M 246 | 1 | 6 mm width | Link (https://s.click.aliexpress.com/e/_c4DlcQaD) |  | Link (https://github.com/Source-Robotics/PAR6-Collaborative-Robot-Arm/blob/main/BOM/BOM%20reference%20images/HTD%203M%20belt.png)
J4/J5 Pulley | HTD3M 12T | 2 | 5mm bore, 10mm width | Link (https://s.click.aliexpress.com/e/_DBVgkVp) |  | Link (https://github.com/Source-Robotics/PAR6-Collaborative-Robot-Arm/blob/main/BOM/BOM%20reference%20images/HTD%203M%20pulley.png)
J1 Pulley | HTD3M 15T | 1 | 5mm bore, 10mm width | Link (https://s.click.aliexpress.com/e/_DBVgkVp) |  | Link (https://github.com/Source-Robotics/PAR6-Collaborative-Robot-Arm/blob/main/BOM/BOM%20reference%20images/HTD%203M%20pulley.png)
Shaft couplers
**Joints 2 and 3 can use different shaft coupler options. Choose only one J2/J3 option below (quantity 2 total). Option 1 gives the best performance if you use the official shaft coupler or machine an equivalent part from the custom and machined parts files. Option 2 is a friction/tension based coupler. Option 3 uses the same coupler as the gripper/flange, but is more prone to slipping and requires the alternative upper arm STL files.** (https://github.com/Source-Robotics/PAR6-Collaborative-Robot-Arm/blob/main/BOM/Custom%20%26%20machined%20parts)
Option | Name | Type | Quantity | Description | Link | ALT link | Reference Image
Option 1 - Recommended Coming soon! | Shaft coupler | For J2 & J3 | 2 | Official or machined D8 oval flange coupler; best performance. See custom and machined parts. (https://github.com/Source-Robotics/PAR6-Collaborative-Robot-Arm/blob/main/BOM/Custom%20%26%20machined%20parts) | Link (https://s.click.aliexpress.com/e/_c3UQtavB) |  | Link (https://github.com/Source-Robotics/PAR6-Collaborative-Robot-Arm/blob/main/BOM/BOM%20reference%20images/source_coupler.png)
Option 2 | Shaft coupler | For J2 & J3 | 2 | Friction/tension based D8 oval flange coupler; easier to source, but can slip more than Option 1 | Link (https://s.click.aliexpress.com/e/_c3UQtavB) |  | Link (https://github.com/Source-Robotics/PAR6-Collaborative-Robot-Arm/blob/main/BOM/BOM%20reference%20images/D8_Oval_flange_coupler.png)
Option 3 | Shaft coupler | For J2 & J3 | 2 | Gripper/flange style coupler; most prone to slipping and requires the alternative upper arm STL files (https://github.com/Source-Robotics/PAR6-Collaborative-Robot-Arm/blob/main/BOM/../3D%20Print%20Files/STL/A4_Upper_arm/Alternative%20files) | Link (https://s.click.aliexpress.com/e/_c2xnQgI7) |  | Link (https://github.com/Source-Robotics/PAR6-Collaborative-Robot-Arm/blob/main/BOM/BOM%20reference%20images/shaft%20coupler%20gripper.png)
Required for grippers and flanges | Shaft coupler | For gripper / flange | 1 | M4 screw holes for the end flange or gripper | Link (https://s.click.aliexpress.com/e/_c2xnQgI7) |  | Link (https://github.com/Source-Robotics/PAR6-Collaborative-Robot-Arm/blob/main/BOM/BOM%20reference%20images/shaft%20coupler%20gripper.png)
Bearings and Mechanical Components
Name | Type | Quantity | Description | Link | ALT link | Reference Image
AXK3552 | AXK3552 needle bearing | 1 | 35X52X4, with plates | Link (https://s.click.aliexpress.com/e/_Dk4bHg7) |  | Link (https://github.com/Source-Robotics/PAR6-Collaborative-Robot-Arm/blob/main/BOM/BOM%20reference%20images/AXK3552%20needle%20bearing.png)
NSK HR32906J | NSK HR32906J Tapered bearing | 5 | Joint 5, 4 and 3 | Link (https://s.click.aliexpress.com/e/_DcJMtBl) |  | Link (https://github.com/Source-Robotics/PAR6-Collaborative-Robot-Arm/blob/main/BOM/BOM%20reference%20images/Tapered%20bearing.png)
NSK HR32907J | NSK HR32907J Tapered bearing | 4 | Joint 1 and 2 | Link (https://s.click.aliexpress.com/e/_DcJMtBl) |  | Link (https://github.com/Source-Robotics/PAR6-Collaborative-Robot-Arm/blob/main/BOM/BOM%20reference%20images/Tapered%20bearing.png)
Tensioning bearing | 3x8x4 | 2 | Ball bearing for belts | Link (https://s.click.aliexpress.com/e/_DCjfgFV) |  | Link (https://github.com/Source-Robotics/PAR6-Collaborative-Robot-Arm/blob/main/BOM/BOM%20reference%20images/small%20tension%20bearings.png)
Tensioning bearing | 3x10x4 | 8 | Ball bearing for belts | Link (https://s.click.aliexpress.com/e/_DlA33Af) |  | Link (https://github.com/Source-Robotics/PAR6-Collaborative-Robot-Arm/blob/main/BOM/BOM%20reference%20images/small%20tension%20bearings.png)
Mechanical Components
Name | Type | Quantity | Description | Link | ALT link | Reference Image
Brass inserts |  | 6 | M3, 5mm len, 4.5 OD, used for Flange | Link (https://s.click.aliexpress.com/e/_c2RX6lzp) |  | Link (https://github.com/Source-Robotics/PAR6-Collaborative-Robot-Arm/blob/main/BOM/BOM%20reference%20images/brass_insert.png)
PCBs
Component | Type | Quantity | Description | Link | ALT link | Reference Image
Closed loop Stepper Drivers | STEPFOC | 6 | Stepper Drivers | Link (https://source-robotics.com/products/stepfoc-stepper-controller) |  | Link (https://github.com/Source-Robotics/PAR6-Collaborative-Robot-Arm/blob/main/BOM/BOM%20reference%20images/STEPFOC%20stepper%20driver.png)
Gripper connector PCB |  | 1 | Source Robotics website only for beta for now | Link (https://github.com/Source-Robotics/PAR6-Collaborative-Robot-Arm/blob/main/BOM/TODO) |  | Link (https://github.com/Source-Robotics/PAR6-Collaborative-Robot-Arm/blob/main/BOM/BOM%20reference%20images/Gripper%20connector%20PCB.jpg)
Hall sensor PCB |  | 1 | Source Robotics website only for beta for now | Link (https://github.com/Source-Robotics/PAR6-Collaborative-Robot-Arm/blob/main/BOM/TODO) |  | Link (https://github.com/Source-Robotics/PAR6-Collaborative-Robot-Arm/blob/main/BOM/BOM%20reference%20images/Hall%20sensor%20PCB.jpg)
Base Distribution PCB |  | 1 | Source Robotics website only for beta for now | Link (https://github.com/Source-Robotics/PAR6-Collaborative-Robot-Arm/blob/main/BOM/TODO) |  | Link (https://github.com/Source-Robotics/PAR6-Collaborative-Robot-Arm/blob/main/BOM/BOM%20reference%20images/Base%20Distribution%20board.jpg)
Electronics
Component | Type | Quantity | Description | Link | ALT link | Reference Image
Motor controller Magnets | Diametrically Magnetised Magnets | 6 | Stepper Drivers encoder magnets | Link (https://source-robotics.com/products/6x2-5mm-diametrical-neodymium-magnet) |  | Link (https://github.com/Source-Robotics/PAR6-Collaborative-Robot-Arm/blob/main/BOM/BOM%20reference%20images/Magnet.png)
Gripper Magnet | Axial Magnetised Magnets (Regular magnet) | 1 |  | Link (https://s.click.aliexpress.com/e/_c4tF3Rzf) |  | Link (https://github.com/Source-Robotics/PAR6-Collaborative-Robot-Arm/blob/main/BOM/BOM%20reference%20images/Magnet.png)
Thermistor | Thermistor NTC 100K 3950 | 6 |  | Link (https://source-robotics.com/products/100k-ntc-thermistor) |  | Link (https://github.com/Source-Robotics/PAR6-Collaborative-Robot-Arm/blob/main/BOM/BOM%20reference%20images/Thermistor.png)
Robot base connector | GX16 4PIN male connector | 1 | Male + Female pair (female part is used in cable making) | Link (https://s.click.aliexpress.com/e/_c3o4afqR) |  | Link (https://github.com/Source-Robotics/PAR6-Collaborative-Robot-Arm/blob/main/BOM/BOM%20reference%20images/GX16.jpg)
E-stop | 19mm | 1 | Emergency switch | Link (https://s.click.aliexpress.com/e/_c3TdMLgT) |  | Link (https://github.com/Source-Robotics/PAR6-Collaborative-Robot-Arm/blob/main/BOM/BOM%20reference%20images/19mm%20ESTOP.png)
Connectors JST ZH 1.5MM 2PIN male |  | 10 | Used to make custom cables | Link (https://s.click.aliexpress.com/e/_c37crJFp) |  | Link (https://github.com/Source-Robotics/PAR6-Collaborative-Robot-Arm/blob/main/BOM/BOM%20reference%20images/Connectors%20JST%20ZH.png)
Connectors JST XH 2.54MM 2PIN male |  | 10 | Used to make custom cables | Link (https://s.click.aliexpress.com/e/_c2xeSW0J) |  | Link (https://github.com/Source-Robotics/PAR6-Collaborative-Robot-Arm/blob/main/BOM/BOM%20reference%20images/Connectors%20JST%20XH.jpg)
Thermal cement |  | 1 | Used to attach thermistor to stepper motor | Link (https://s.click.aliexpress.com/e/_c3t5DkcN) |  | Link (https://github.com/Source-Robotics/PAR6-Collaborative-Robot-Arm/blob/main/BOM/BOM%20reference%20images/Thermal%20cement.jpg)
Wires / Cables
[!IMPORTANT] **If you dont want to build the wires yourself you can get the wire pack from our store (Coming soon)**
**With wires make sure you follow proper orientation of the connector heads when ordering!** (https://github.com/Source-Robotics/PAR6-Collaborative-Robot-Arm/blob/main/BOM/BOM%20reference%20images/ZH_XH_cable_direction.png)
[!IMPORTANT] **Cable building guide is here** (https://github.com/Source-Robotics/PAR6-Collaborative-Robot-Arm/blob/main/BOM/../Assembly%20manual/Building_cables.md)
[!IMPORTANT] **If you dont want to build the cables yourself you can get the cable pack from our store (Coming soon)**
Name | Type | Quantity | Description | Link | ALT link | Reference Image
JST ZH 1.5MM 2PIN female-female 20-30cm |  | 3 | J5 motor - J6 motor, Gripper connector PCB - J4 wire, J4 motor - Extension wire J6,5,4 | Link (https://s.click.aliexpress.com/e/_c4CyWKe1) |  | Link (https://github.com/Source-Robotics/PAR6-Collaborative-Robot-Arm/blob/main/BOM/BOM%20reference%20images/ZH_XH_cable_direction.png)
JST XH 2.54MM 2PIN female-female 20-30cm |  | 3 | J5 motor - J6 motor, Gripper connector PCB - J4 wire, J4 motor - Extension wire J6,5,4 | Link (https://s.click.aliexpress.com/e/_c4CyWKe1) |  | Link (https://github.com/Source-Robotics/PAR6-Collaborative-Robot-Arm/blob/main/BOM/BOM%20reference%20images/ZH_XH_cable_direction.png)
JST ZH 1.5MM 2PIN female-male 23cm | Extension wire (best to build your own) | 2 | J5 motor - J6 motor, J4 wire - J4 motor | [Link]() |  | Link (https://github.com/Source-Robotics/PAR6-Collaborative-Robot-Arm/blob/main/BOM/BOM%20reference%20images/ZH_series_extension_cable.png)
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

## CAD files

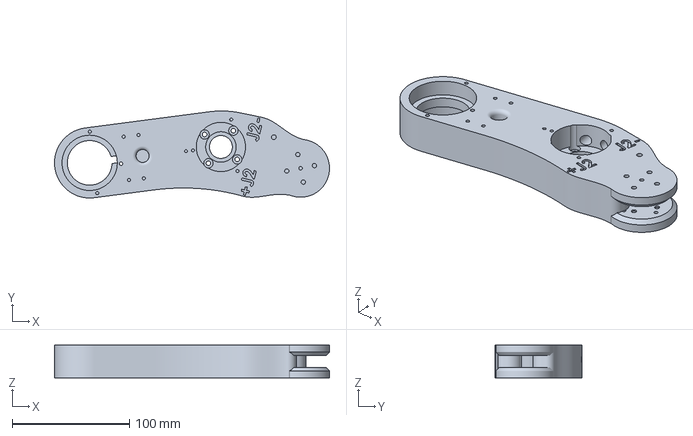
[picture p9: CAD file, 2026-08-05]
3D Print Files/3MF/250x210mm/Multi color/Plate 5.3mf
234.6 x 74.2 x 28.0 mm

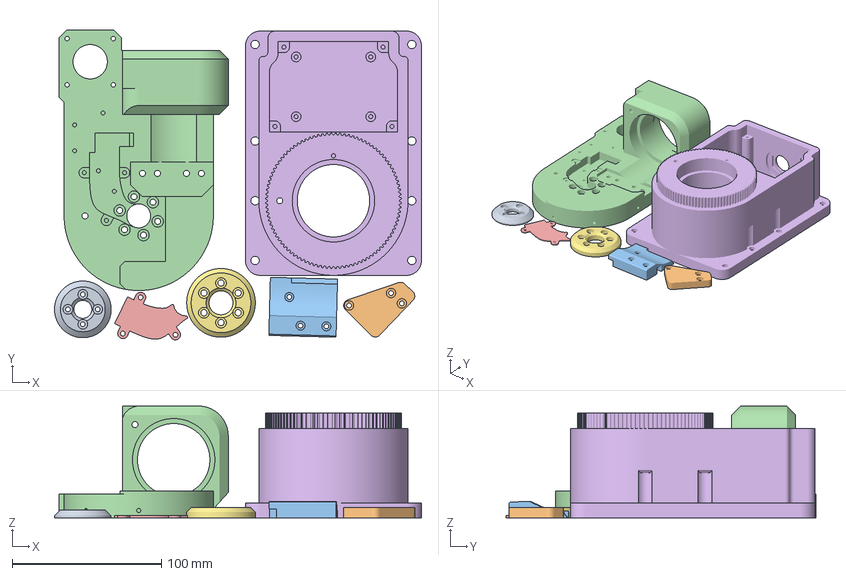
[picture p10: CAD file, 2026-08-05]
3D Print Files/3MF/250x210mm/Single color/Plate 2.3mf
245.9 x 207.6 x 75.0 mm
J4_bearing_backplate.STL
Elbow_blocker.STL
J2_blocker.STL
Turret.STL
Turret_wire_cover.STL
Base.STL
Base_bearing_backplate.STL

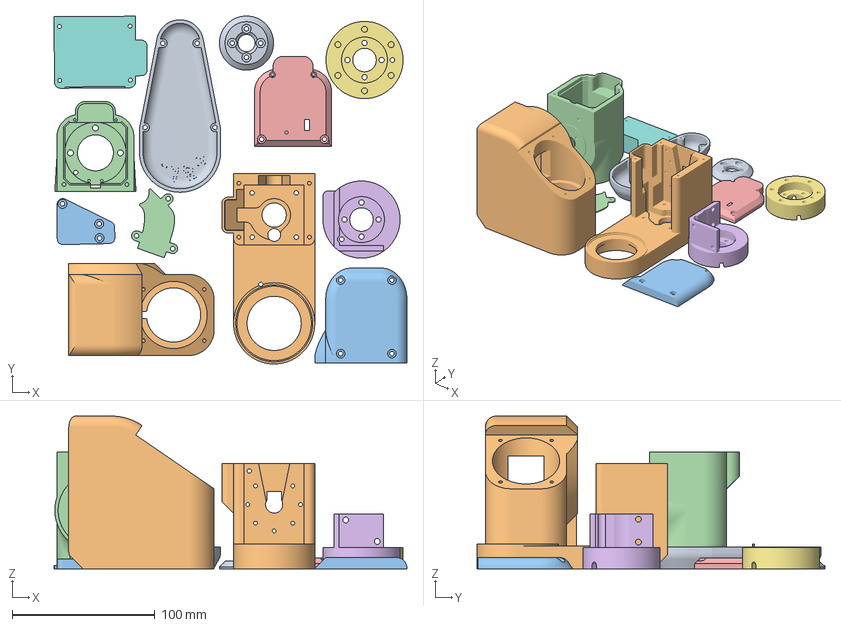
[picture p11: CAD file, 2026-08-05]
3D Print Files/3MF/250x250mm/Multi color/Plate 1.3mf
247.5 x 244.1 x 107.2 mm
J5_belt_lid_multicolor
Elbow_part.STL
Elbow_lid.STL
Wrist.STL
Wrist_lid.STL
Pneumatic_gripper_holder_MHZ2-16D.STL
PAR6_flange.STL
electronics_lid_lower_arm_basic.STL
J4_bearing_backplate.STL
J5_part.STL
Elbow_blocker.STL
Turret_wire_cover.STL

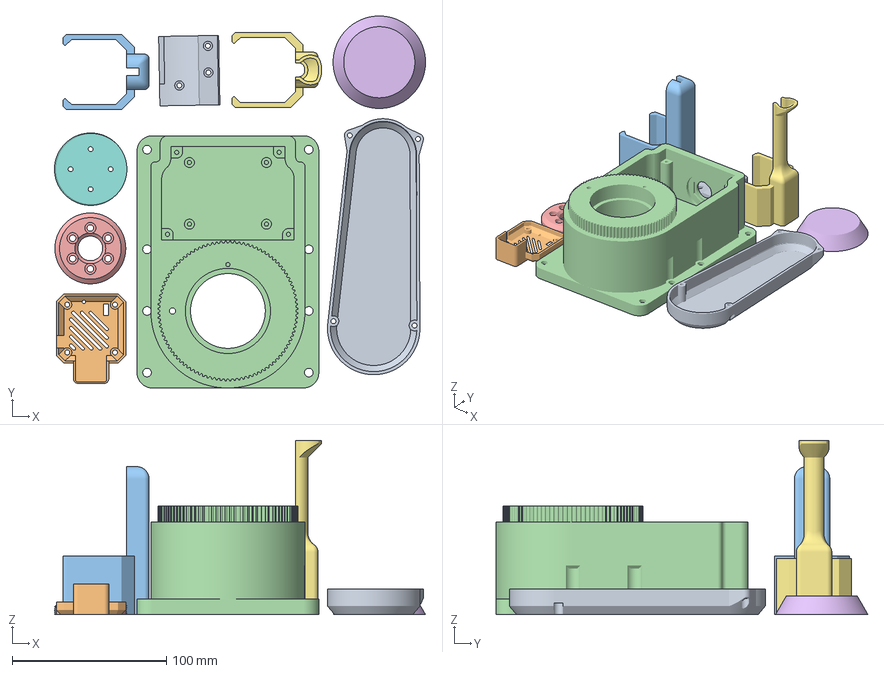
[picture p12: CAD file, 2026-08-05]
3D Print Files/3MF/250x250mm/Single color/Plate 2.3mf
240.8 x 241.4 x 113.0 mm
J2_blocker.STL
stepper_lid_J2.STL
Stepper_sleeve_J1.STL
Base.STL
Base_bearing_backplate.STL
J2_cover.STL
Stepper_sleeve_J3.STL
J2_bearing_backplate.STL
Upper_arm_cover.STL

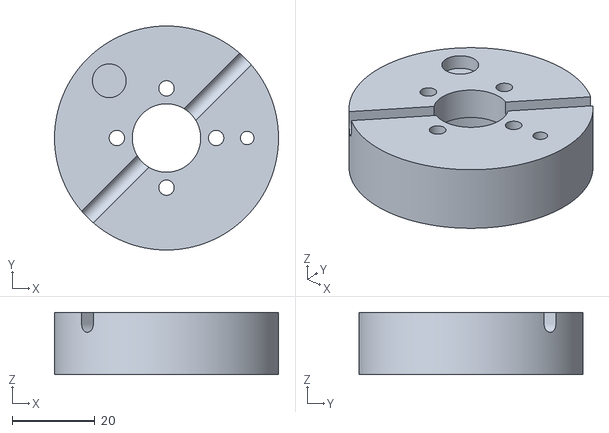
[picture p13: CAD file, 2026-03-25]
3D Print Files/STL/A0_End_effector/PAR6_flange.STL
54.1 x 54.1 x 15.0

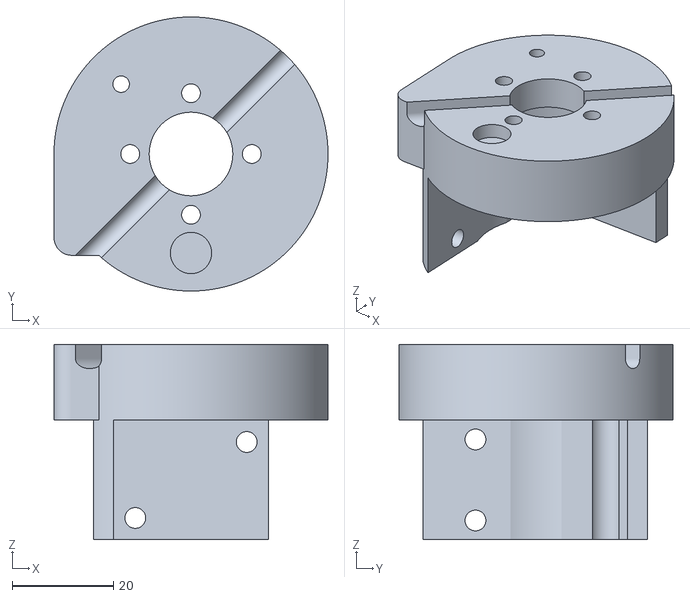
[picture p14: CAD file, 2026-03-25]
3D Print Files/STL/A0_End_effector/Pneumatic grippers/Pneumatic_gripper_holder_MHZ2-16D.STL
54.1 x 54.1 x 38.6

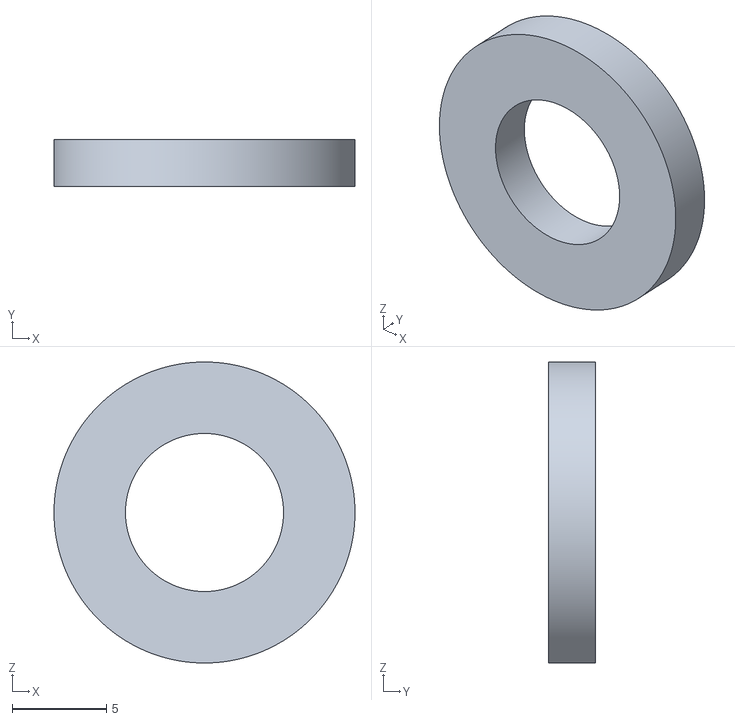
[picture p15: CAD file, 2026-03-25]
3D Print Files/STL/A0_End_effector/SSG48 gripper needed parts/SSG48_gripper_spacer.STL
16.0 x 2.50 x 16.0

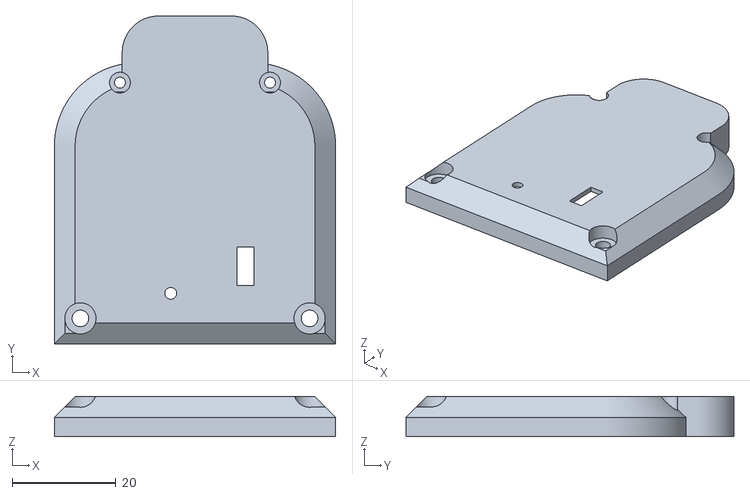
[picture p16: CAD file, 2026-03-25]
3D Print Files/STL/A1_Wrist/Wrist_lid.STL
54.1 x 63.1 x 7.70

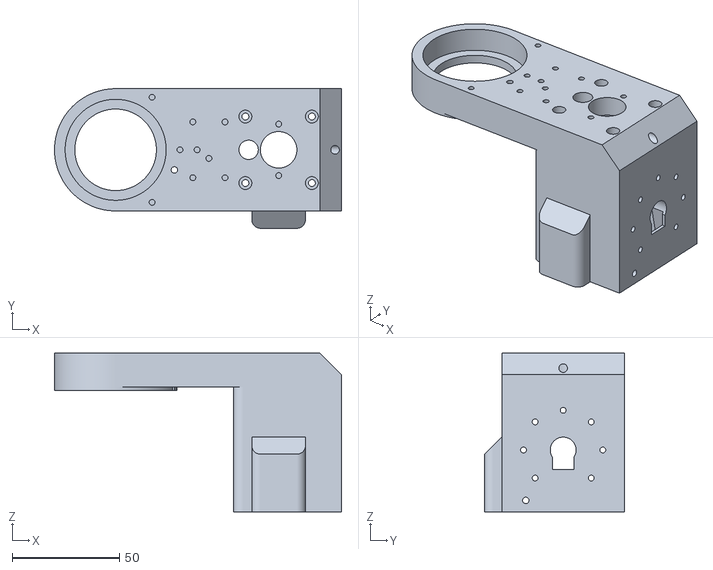
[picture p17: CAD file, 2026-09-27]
3D Print Files/STL/A2_Lower_arm/J5_part.STL
133.8 x 65.1 x 74.0

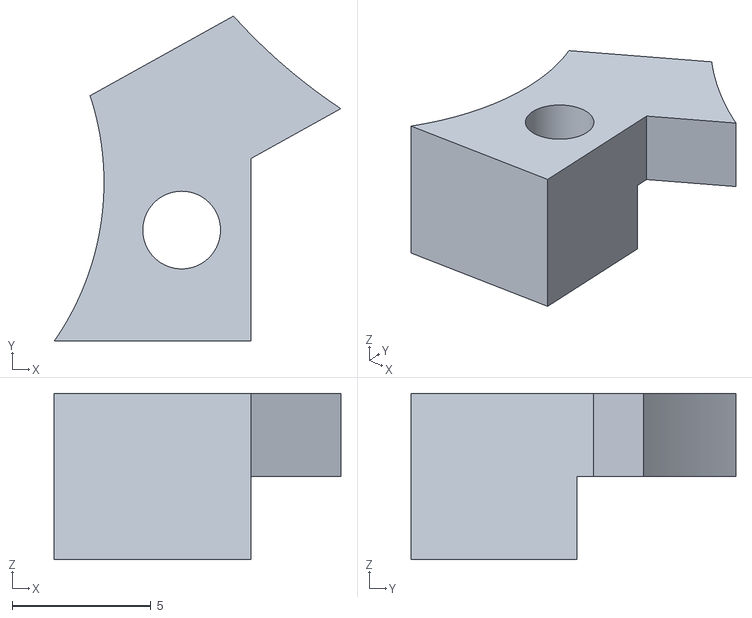
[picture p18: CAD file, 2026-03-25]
3D Print Files/STL/A3_Elbow/J4_limiter.STL
10.3 x 11.7 x 6.00

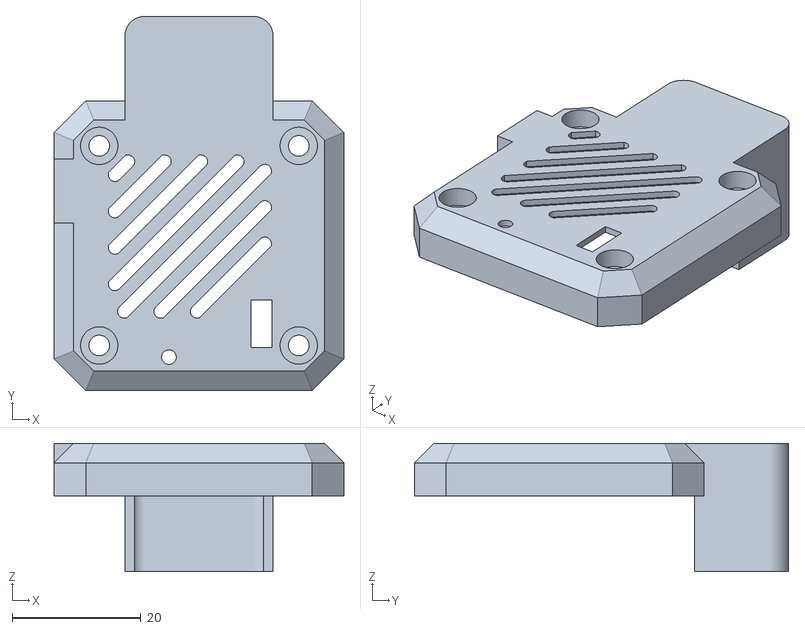
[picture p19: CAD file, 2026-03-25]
3D Print Files/STL/A4_Upper_arm/stepper_lid_J3.STL
45.0 x 58.1 x 19.9

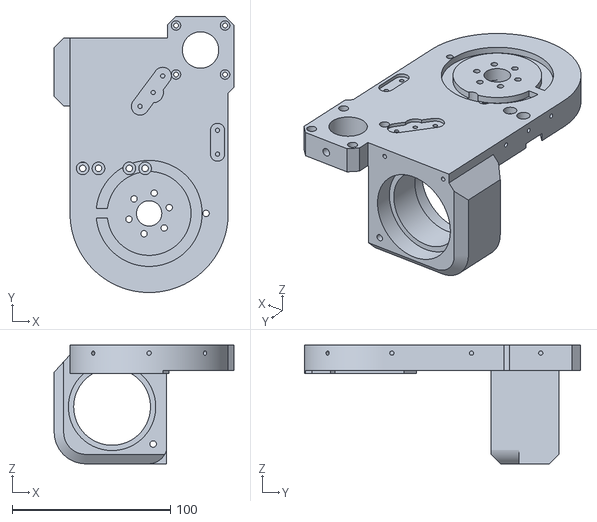
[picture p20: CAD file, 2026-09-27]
3D Print Files/STL/A5_Shoulder/Turret.STL
113.5 x 174.5 x 75.0

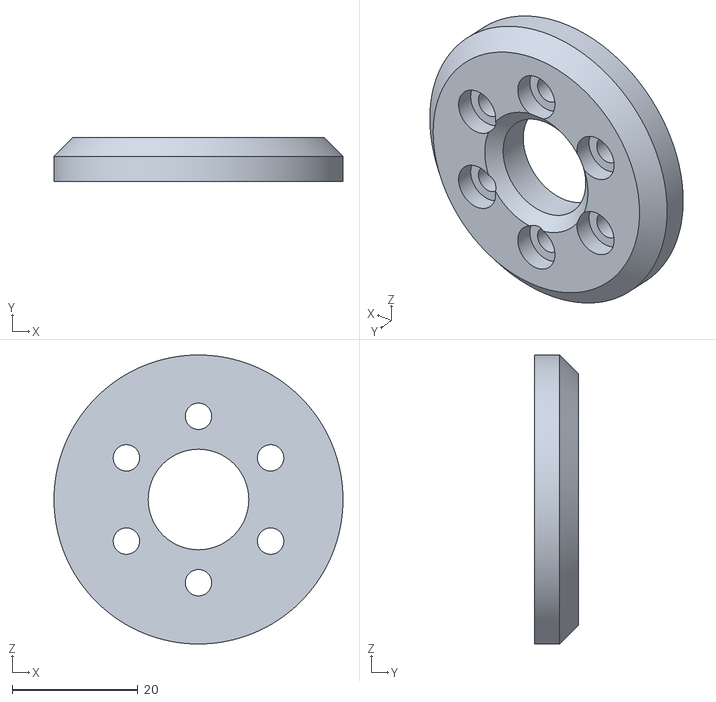
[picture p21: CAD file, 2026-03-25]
3D Print Files/STL/A6_Base/Base_bearing_backplate.STL
46.0 x 7.00 x 46.0

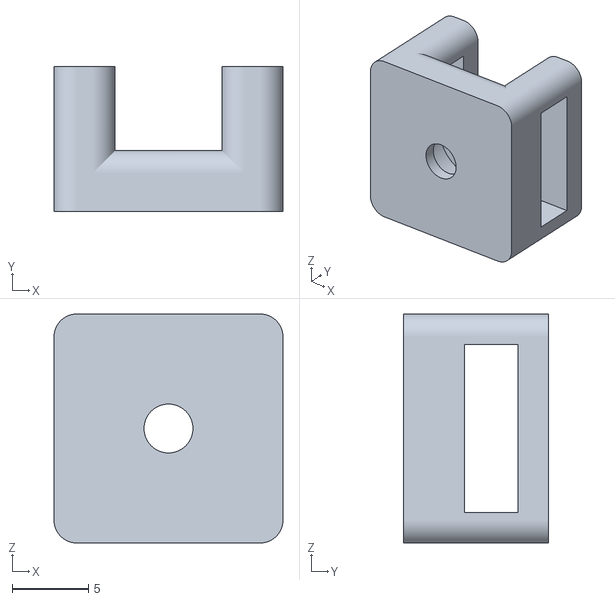
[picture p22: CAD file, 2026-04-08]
3D Print Files/STL/Miscellaneous/Cable_tie_mount.STL
15.0 x 9.50 x 15.0

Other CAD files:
3D Print Files/STL/Miscellaneous/CNC_metal_plates/big_base.STEP
3D Print Files/STL/Multicolor prints/J5_LID/J5_belt_lid_multicolor.gcode.3mf
3D Print Files/STL/Multicolor prints/Upper_arm_cover/Upper_arm_cover_LOGO_latest.3mf
3D Print Files/STL/Stepper motor accessories/MG_series_gearbox_extender.STL
3D Print Files/3MF/250x210mm/Multi color/Plate 1.3mf
3D Print Files/3MF/250x210mm/Multi color/Plate 3.3mf
3D Print Files/3MF/250x210mm/Multi color/Plate 4.3mf
3D Print Files/3MF/250x210mm/Multi color/Plate 6.3mf
3D Print Files/3MF/250x210mm/Single color/Plate 3.3mf
3D Print Files/3MF/250x210mm/Single color/Plate 4.3mf
3D Print Files/3MF/250x210mm/Single color/Plate 6.3mf
3D Print Files/3MF/250x250mm/Multi color/Plate 2.3mf
3D Print Files/3MF/250x250mm/Multi color/Plate 3.3mf
3D Print Files/3MF/250x250mm/Multi color/Plate 4.3mf
3D Print Files/3MF/250x250mm/Multi color/Plate 5.3mf
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

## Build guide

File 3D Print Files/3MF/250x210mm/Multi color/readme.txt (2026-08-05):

Plate 1 : 25% infill
Plate 2 : 25% infill
Plate 3 : 25% infill
Plate 4 : 25% infill
Plate 5 : 35% infill, prohibited supports inside of the part
Plate 6 : 50% infill

All others parameters are common and can be found in "3D Print Files/PAR6 Print Table.pdf".
Every plate has been manually sliced and verified using the integrated profile and using Prusa MK4S printer profile.

This folder contains both single and multi color parts (plate 1 and 3).

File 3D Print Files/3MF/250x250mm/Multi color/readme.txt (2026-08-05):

Plate 1 : 25% infill
Plate 2 : 25% infill
Plate 3 : 25% infill
Plate 4 : 35% infill, prohibited supports inside of the part
Plate 5 : 50% infill

All others parameters are common and can be found in "3D Print Files/PAR6 Print Table.pdf".
Every plate has been manually sliced and verified using the integrated profile and using Anycubic Kobra 3 printer profile.

This folder contains both single and multi color parts (plate 1 and 2).

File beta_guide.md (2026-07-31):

# Beta Guide

## OS
https://github.com/ros-realtime/ros-realtime-rpi4-image/releases/tag/24.04.2_v6.8.4-rt11-raspi_ros2_jazzy

## Beta RCB motherboard
**The mainboard have some modifications on them, cut traces or soldered wires. DO NOT remove or try to fix them this beta batch of pcbs had some mistakes that were fixed that way!**

## Setting up the motors with motorgui.com

* Go to [motorgui.com](motorgui.com)
* Go to the update firmware tab. Connect via USB to serial adapter to your driver
* Flash the latest firmware for stepfoc
* Exit firmware update, connect to gui via uart transport on the panel on the left side.
* Apply #default to your motor
* Go to preset tab and apply preset depending on what motor you are using. (preset for J1 is is Joint 1 (base) and so on...)
* #Save that
* In tune & calibrate press "Run #Cal" and calibrate your motor
* #Save 
* Do this for each of the PAR6 motors

## Beta RCB Mainboard — What to Expect
The PCBs ship flashed with RCB code (release v0, available on GitHub) and have been lightly tested. As an early v0 batch, the PCBs have some visible modifications — removed traces and jumper wires — that are required for proper operation. These do not affect the robot's performance.
Below is a summary of the known issues, all of which have been addressed on the boards before shipping:
K1 footprint / relay — Wrong footprint; relay is closed by default on power-on (should be open)
Q1 — Requires a jumper wire
D11 & D12 — Require jumper wires
E-stop connectors — Wiring is swapped; 2 E-stop pins need to be connected across the 2 connectors
R63 — Swapped to 1.47 kΩ
Trace cuts — Some traces need to be cut for proper operation (between the 2 green connectors and near J19)

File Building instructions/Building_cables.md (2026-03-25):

# PAR6 cables

PAR6 robotic arm uses 2 types of cables:
* JST XH series for power delivery to motor drivers - 24 AWG or 22 AWG
* JST ZH series for CAN comms between motor drivers - 28 AWG

> [!NOTE]
>     **It is recommended to twist all CAN bus cables**

> [!WARRNING]
>     **If you are unsure if cables you bought from 3rd party stores are good orientation, lenght or type we recommended buying them from our store. Using wrong cables will damage and destroy your robot.**

If you want to build your own cables this document will provide you with a quick guide on how to build them.

Watch this video on cable assembly

## XH & ZH dual female head cables
These cables need to follow the **wiring diagram** (How wires are connected to the head) shown below! 



These cables can be bought from multiple stores in different sizes.
Sizes we need for PAR6 are:
* 2 x 10cm XH dual female head/plug connector
* 2 x 10cm ZH dual female head/plug connector

* x x 23cm (difficult size to find use 25 or 30)

## XH series extension cables

Parts needed:
* XH male connector
* XH female - female wire (or female - bare wire)
* Heat shrink tube

Cut one end of the XH female-female wire and keep the wire length at around 23cm.
Place heat shrink on the wires. Solder male XH connector to the wires. Follow the orientations on the image below. Heat the heat shrink tubes.

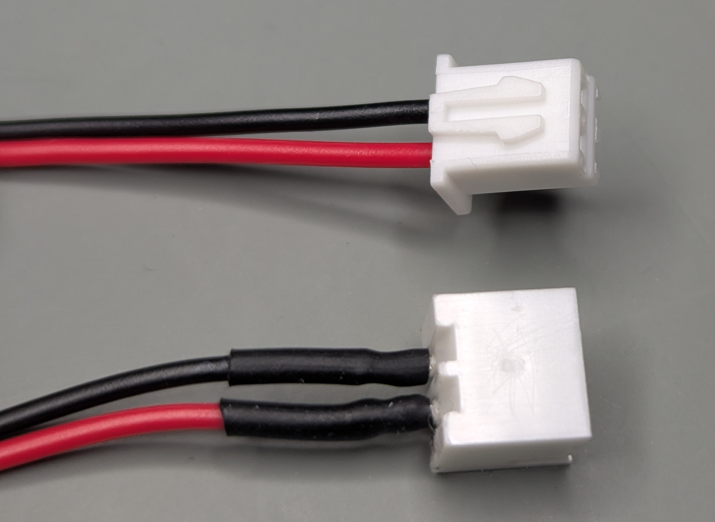
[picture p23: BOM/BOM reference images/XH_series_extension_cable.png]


## ZH series extension cables

Parts needed:
* ZH male connector
* ZH female - female wire (or female - bare wire)
* Heat shrink tube

Cut one end of the ZH female-female wire and keep the wire length at around 23cm.
Place heat shrink on the wires. Solder male ZH connector to the wires. Follow the orientations on the image below. Heat the heat shrink tubes.

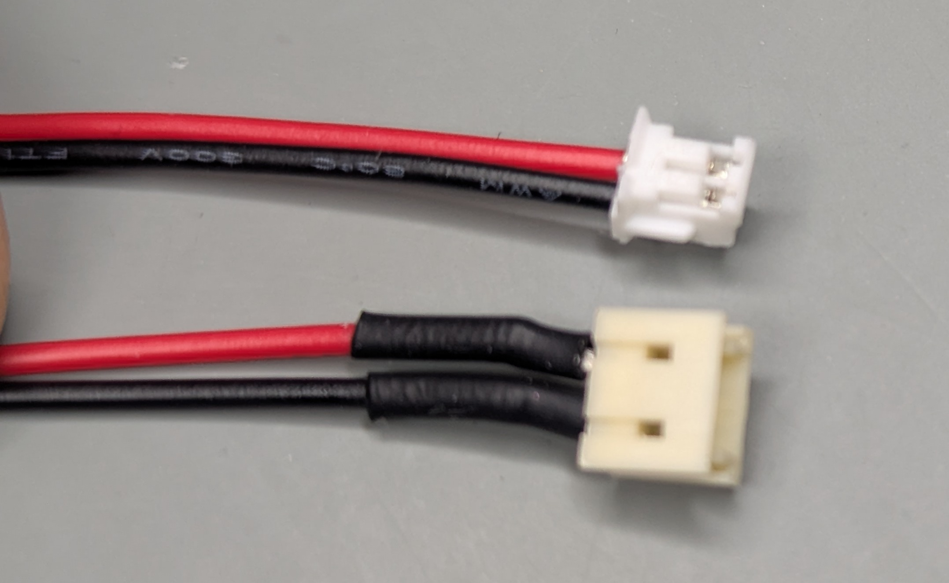
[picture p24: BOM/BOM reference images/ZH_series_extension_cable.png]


## Motor to Base Distribution PCB wire

These wires have a female head on one side and bare wires on the another. They connect directly to the Base Distribution PCB.

Parts needed:
* ZH female-female wire or female - bare wire 

Cut one end of the wire and keep the length of the wire at around **50cm**.

## Extension wire base -  Base Distribution PCB

These wires have a male head connector on one side and bare wires on the another. They connect directly to the Base Distribution PCB.

Parts needed:
* XH male connector
* ZH male connector
* Bare wires (2 colors black and white 24 AWG)

Solder male connectors the same way as when building ZH or XH extenstion cables. 

## PAR6 Robot cable (Robot base to RCB (Robot Control Box) cable)

Parts needed:
* [2 x GX16 4PIN connector female](https://s.click.aliexpress.com/e/_c3o4afqR)
* [Twisted Pair Shielded Cable 4 cores - 24AWG or 22AWG](https://s.click.aliexpress.com/e/_c34NcZIT)

Check the video tutorial [here](TODO)

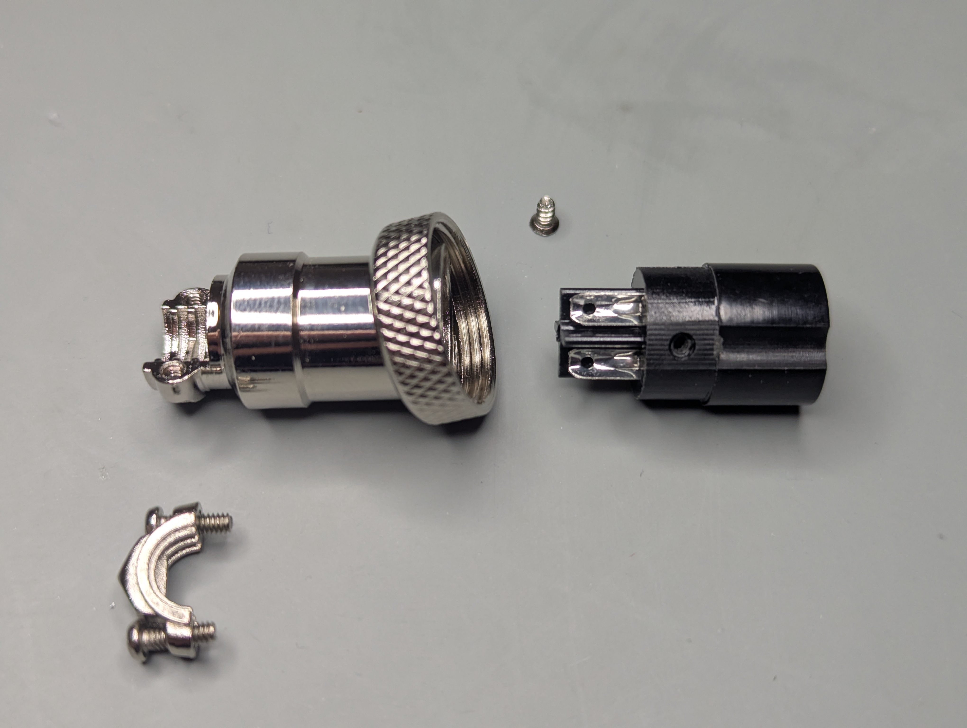
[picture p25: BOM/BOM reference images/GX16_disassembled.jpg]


**Dissasemble the connector.**

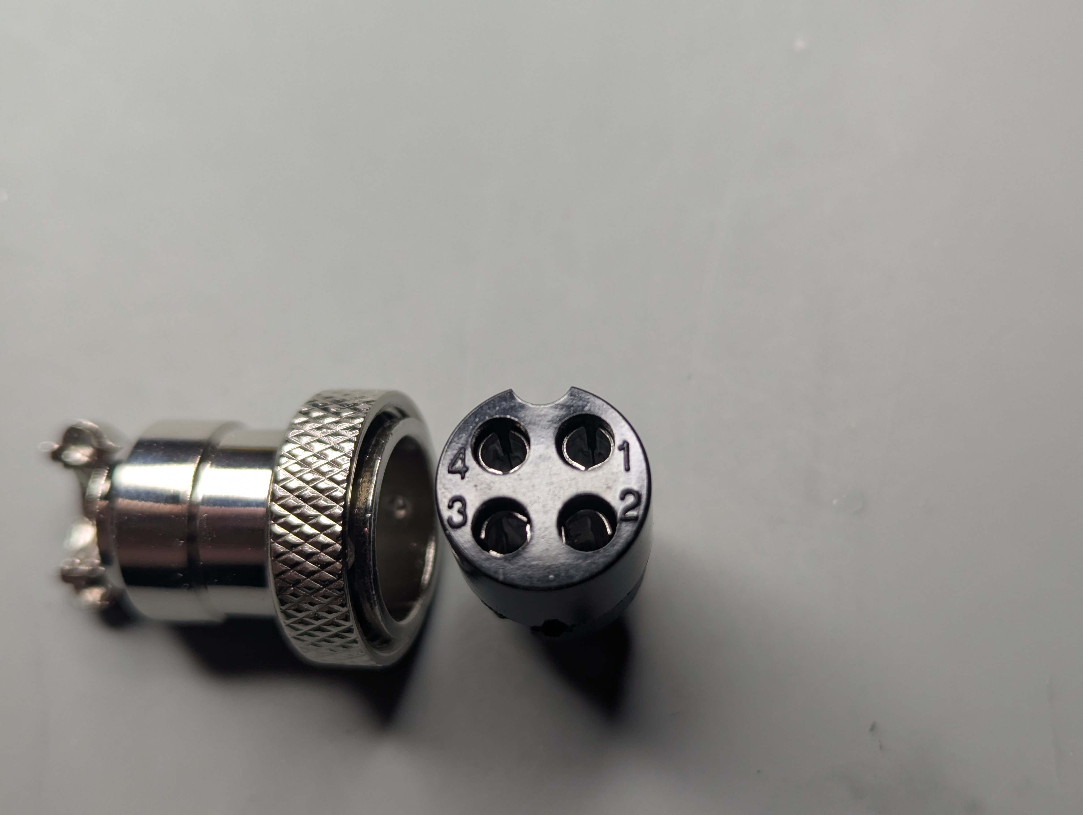
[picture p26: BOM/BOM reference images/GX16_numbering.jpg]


**Connector has numbering on both sides.** 

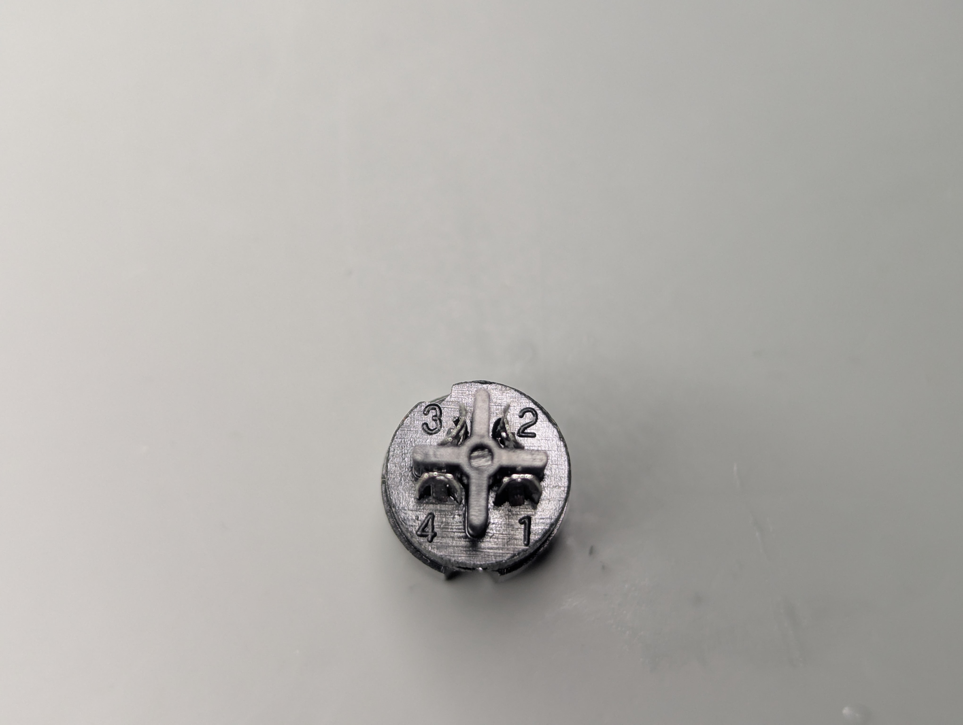
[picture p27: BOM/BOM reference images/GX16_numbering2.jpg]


**When assembling the cable you solder pins 1-1, 2-2, 3-3, 4-4. Do that for the both sides of the cable!** 

> [!NOTE]
>     **Pins 1-4 need to be one wisted wire pair and pins 2-3 need to be another pair!**

## Robot base connector

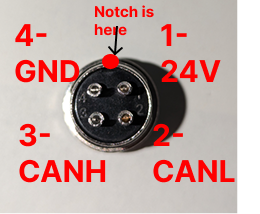
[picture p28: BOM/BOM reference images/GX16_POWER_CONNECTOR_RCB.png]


On the robot arm side and Robot Control Box side the we use this pinout for X16 male connector!

Solder XH wire to the pins 1 and 4. Solder ZH CAN wires to pints 3 and 2. Keep wire length at around 10cm

## MSG & SSG48 gripper cable

Buy Official cables from Source Robotics: [Link](TODO)

Parts needed if DIY your own cable:

| Type | Length / Spec | Quantity | Description | Link |
|---|---|---|---|---|
| 26 AWG cable | 0.15 mm², 4-wire twisted pair | 0.4 m | ~40 cm usually sufficient | [Link](https://s.click.aliexpress.com/e/_c4m3ggwn) |
| M8 4-pin male wire connector | — | 1 | [See reference image](../BOM/BOM%20reference%20images/M8%20male.png) |[Link](https://s.click.aliexpress.com/e/_c4OWHPKF) |
| M8 4-pin female wire connector | — | 1 | [See reference image](../BOM/BOM%20reference%20images/M8_female.png) | [Link](https://s.click.aliexpress.com/e/_c4OWHPKF) |

> [!NOTE]
>     **PAROL6 and PAR6 use different cables for SSG48 and MSG grippers. Using incorrect one can damage your robot**

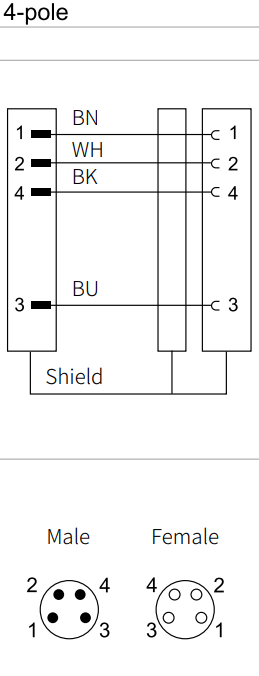
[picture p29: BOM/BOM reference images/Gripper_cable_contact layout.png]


End result of this cable assembly needs to look like this:

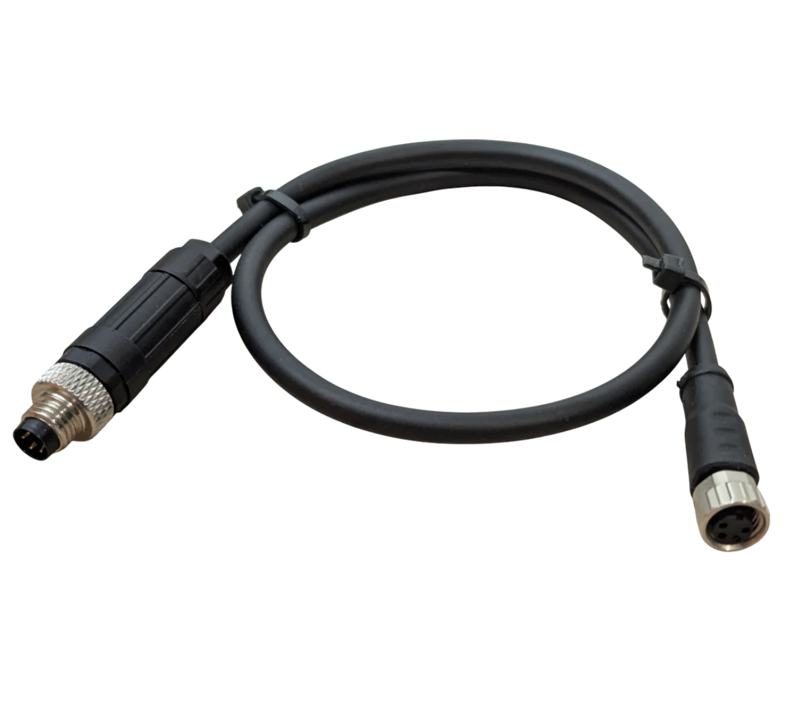
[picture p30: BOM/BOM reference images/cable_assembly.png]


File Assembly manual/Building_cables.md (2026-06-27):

# PAR6 cables

PAR6 robotic arm uses 2 types of cables:
* JST XH series for power delivery to motor drivers - 24 AWG or 22 AWG
* JST ZH series for CAN comms between motor drivers - 28 AWG

> [!NOTE]
>     **It is recommended to twist all CAN bus cables**

> [!WARRNING]
>     **If you are unsure if cables you bought from 3rd party stores are good orientation, lenght or type we recommended buying them from our store. Using wrong cables will damage and destroy your robot.**

If you want to build your own cables this document will provide you with a quick guide on how to build them.

Watch this video on cable assembly

## XH & ZH dual female head cables
These cables need to follow the **wiring diagram** (How wires are connected to the head) shown below! 



These cables can be bought from multiple stores in different sizes.
Sizes we need for PAR6 are:
* 2 x 10cm XH dual female head/plug connector
* 2 x 10cm ZH dual female head/plug connector

* x x 23cm (difficult size to find use 20 or 30)

## XH series extension cables

[Video reference](https://youtu.be/GOb1vQsjfOs)

Parts needed:
* XH male connector
* XH female - female wire (or female - bare wire)
* Heat shrink tube

Cut one end of the XH female-female wire and keep the wire length at around 23cm.
Place heat shrink on the wires. Solder male XH connector to the wires. Follow the orientations on the image below. Heat the heat shrink tubes.



## ZH series extension cables

[Video reference](https://youtu.be/GOb1vQsjfOs)

Parts needed:
* ZH male connector
* ZH female - female wire (or female - bare wire)
* Heat shrink tube

Cut one end of the ZH female-female wire and keep the wire length at around 23cm.
Place heat shrink on the wires. Solder male ZH connector to the wires. Follow the orientations on the image below. Heat the heat shrink tubes.



## Motor to Base Distribution PCB wire

These wires have a female head on one side and bare wires on the another. They connect directly to the Base Distribution PCB.

Parts needed:
* ZH female-female wire or female - bare wire 
* XH female-female wire or female - bare wire 

Cut one end of the wire and keep the length of the wire at around **50cm**.

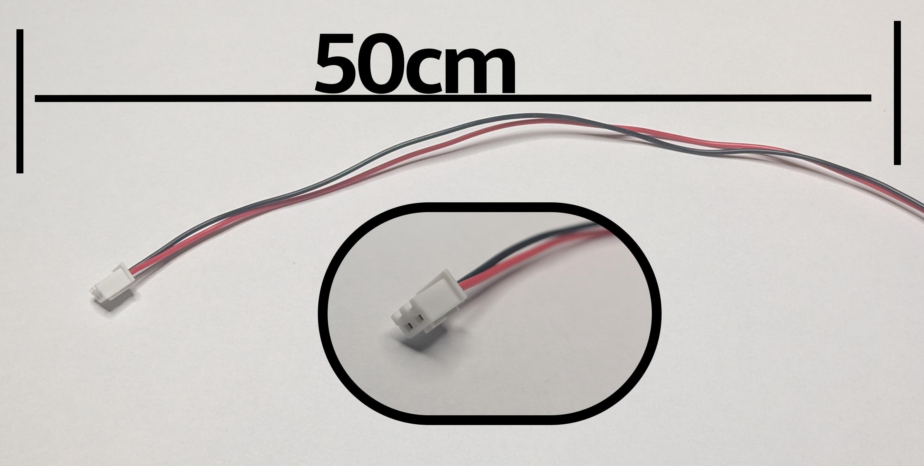
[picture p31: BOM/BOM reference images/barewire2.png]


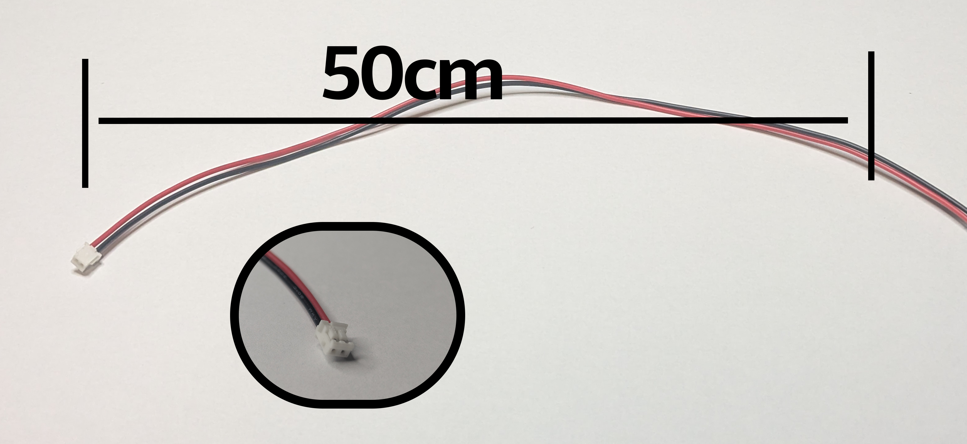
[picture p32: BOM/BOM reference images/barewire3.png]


## Extension wire J6,5,4 -  Base Distribution PCB

These wires have a male head connector on one side and bare wires on the another. They connect directly to the Base Distribution PCB.

Parts needed:
* XH male connector
* ZH male connector
* Bare wires (2 colors, 24 AWG)

Solder male connectors the same way as when building ZH or XH extenstion cables. 

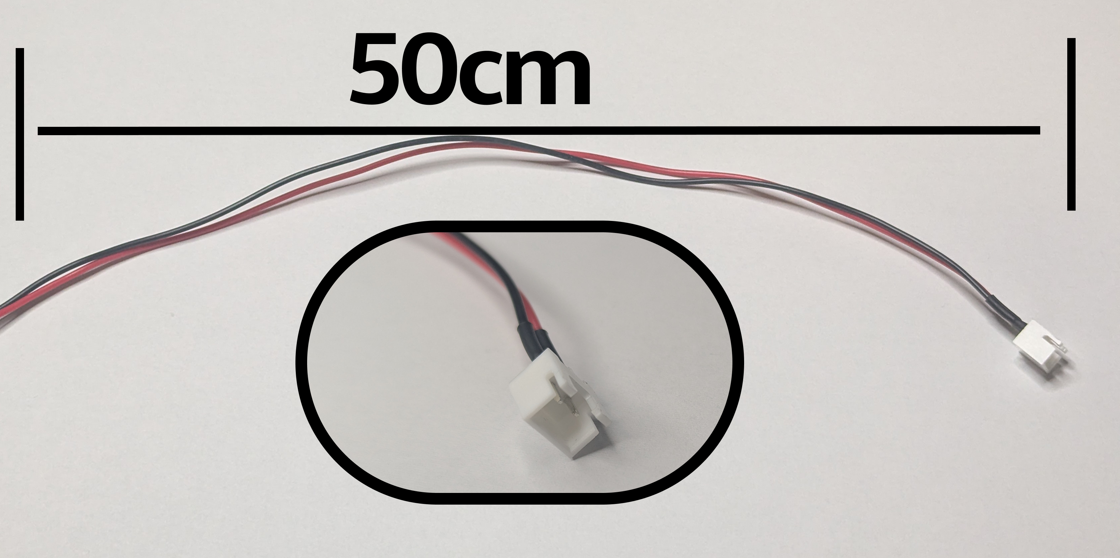
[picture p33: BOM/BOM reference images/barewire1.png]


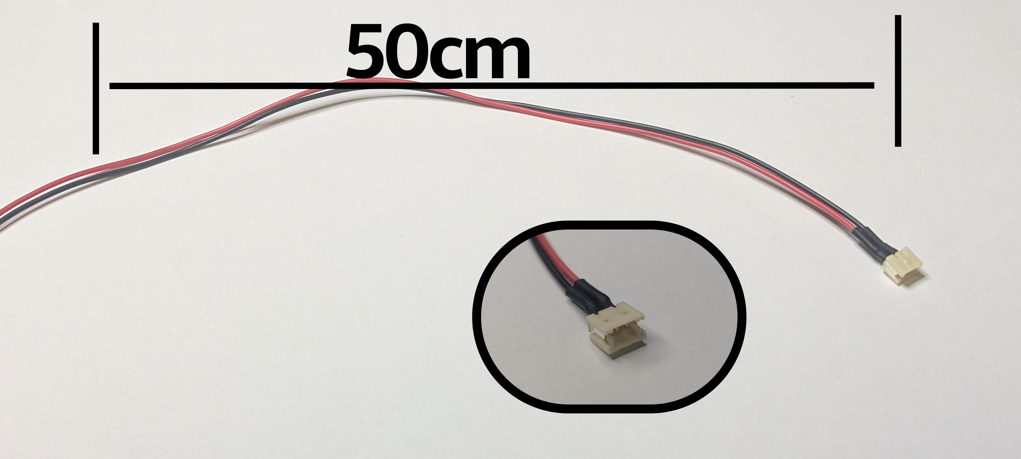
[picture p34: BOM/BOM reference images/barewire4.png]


## PAR6 Robot cable (Robot base to RCB (Robot Control Box) cable)

[Video reference](https://youtu.be/QlNfWAga1l0)

Parts needed:
* [2 x GX16 4PIN connector female](https://s.click.aliexpress.com/e/_c3o4afqR)
* [Twisted Pair Shielded Cable 4 cores - 24AWG or 22AWG](https://s.click.aliexpress.com/e/_c34NcZIT)

Check the video tutorial [here](TODO)



**Dissasemble the connector.**



**Connector has numbering on both sides.** 



**When assembling the cable you solder pins 1-1, 2-2, 3-3, 4-4. Do that for the both sides of the cable!** 

> [!NOTE]
>     **Pins 1-4 need to be one wisted wire pair and pins 2-3 need to be another pair!**

## Robot base connector



On the robot arm side and Robot Control Box side the we use this pinout for X16 male connector!

Solder Power wires to the pins 1 and 4. Solder CAN wires to pints 3 and 2. Keep wire length at around 10cm

## MSG & SSG48 gripper cable

Buy Official cables from Source Robotics: [Link](TODO)

Parts needed if DIY your own cable:

| Type | Length / Spec | Quantity | Description | Link |
|---|---|---|---|---|
| 26 AWG cable | 0.15 mm², 4-wire twisted pair | 0.4 m | ~40 cm usually sufficient | [Link](https://s.click.aliexpress.com/e/_c4m3ggwn) |
| M8 4-pin male wire connector | — | 1 | [See reference image](../BOM/BOM%20reference%20images/M8%20male.png) |[Link](https://s.click.aliexpress.com/e/_c4OWHPKF) |
| M8 4-pin female wire connector | — | 1 | [See reference image](../BOM/BOM%20reference%20images/M8_female.png) | [Link](https://s.click.aliexpress.com/e/_c4OWHPKF) |

> [!NOTE]
>     **PAROL6 and PAR6 use different cables for SSG48 and MSG grippers. Using incorrect one can damage your robot**



End result of this cable assembly needs to look like this:



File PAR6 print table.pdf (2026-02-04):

Printer we used is prusa MK4; default prusament PETG filament profile. If you want your PAR6 robot to function properly you need to try to match these print settings in the table on your printer. Mass does not need to be matched exactly for every

### part but aim for the values listed in this table once your model is sliced!

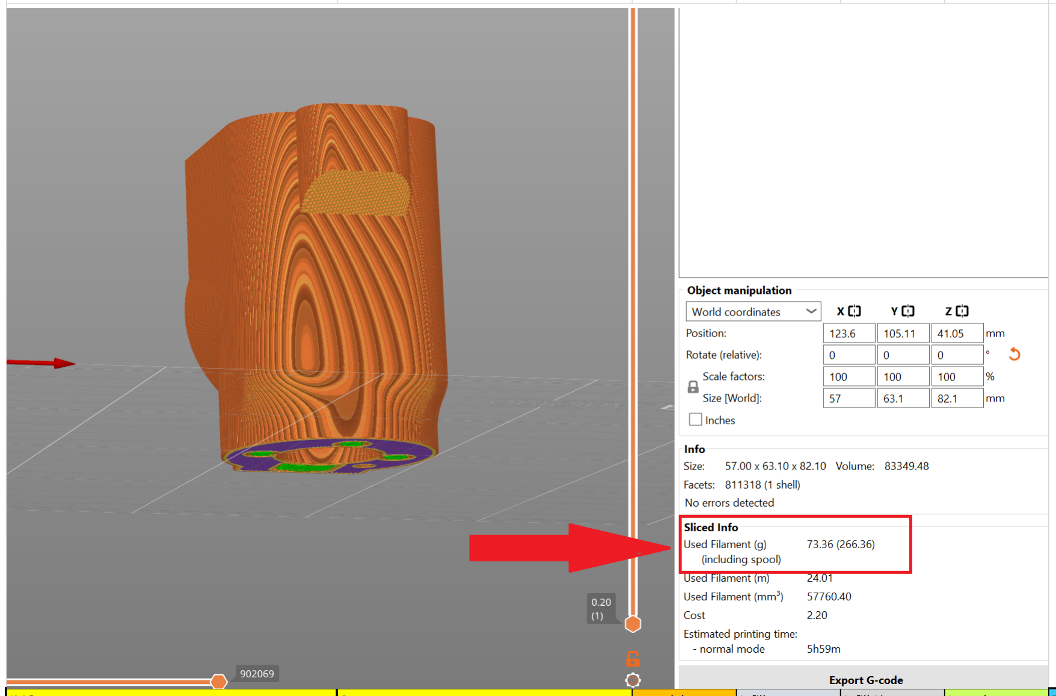
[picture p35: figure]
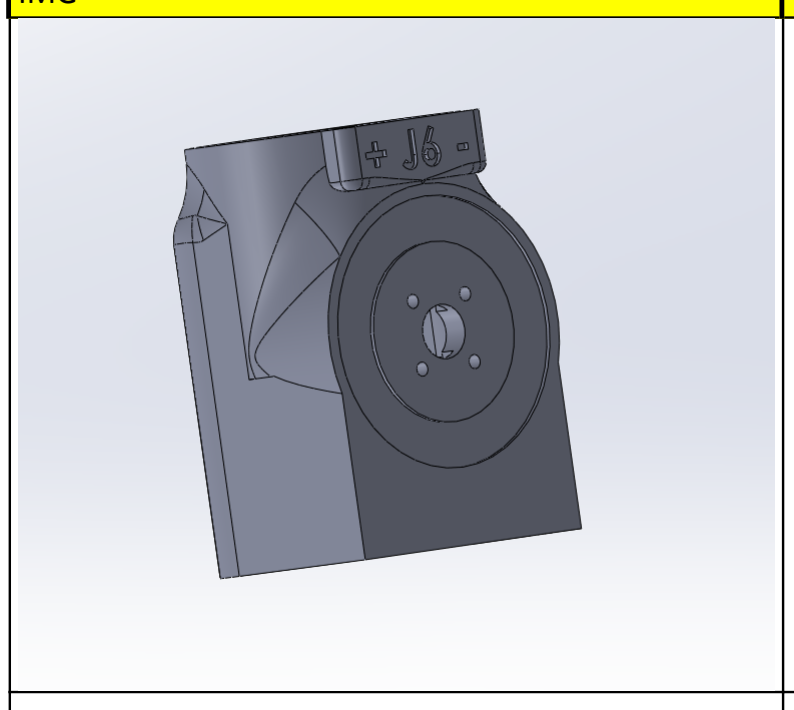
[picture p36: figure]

IMG | Part name | mass (g) | Infill type | Infill % | Layer h | Top layers | Bot layers | Perimeters
| Wrist | 70 | honey | 25 | 0.15 | 6 | 5 | 3

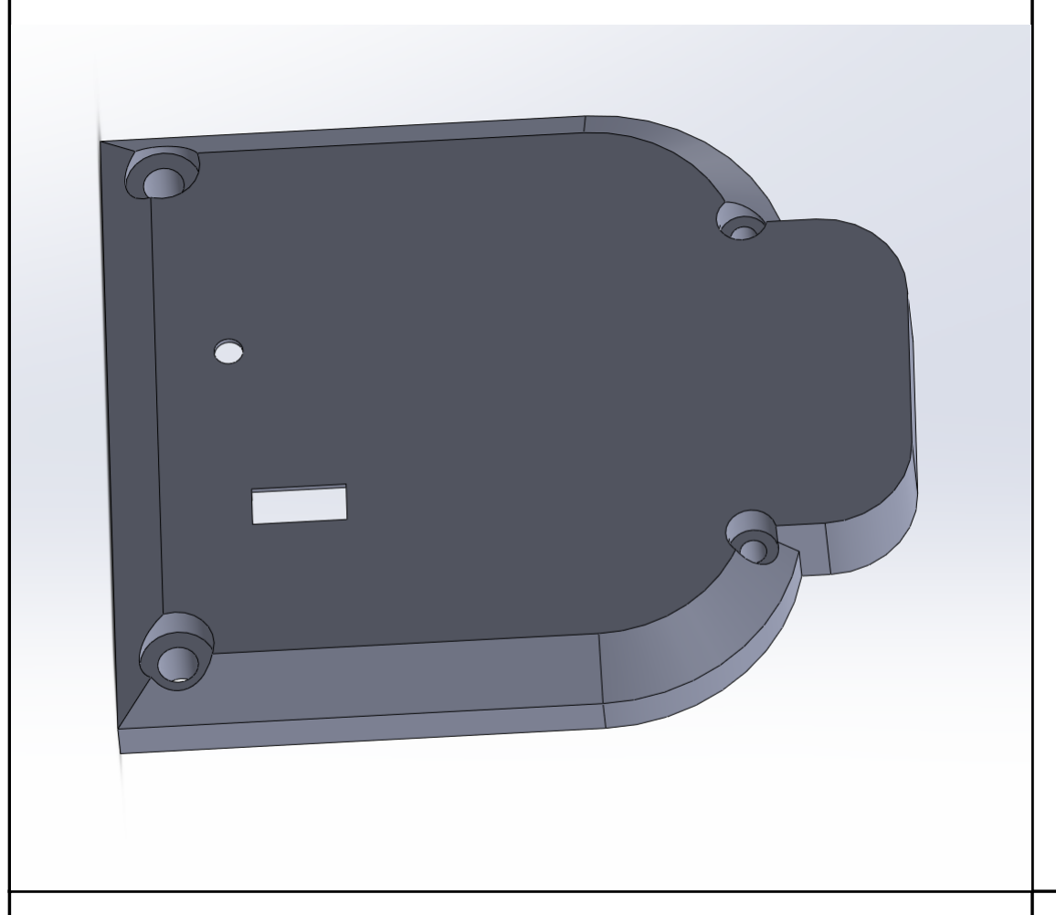
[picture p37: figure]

| Wrist lid | 8.3 | honey | 25 | 0.15 | 6 | 5 | 3

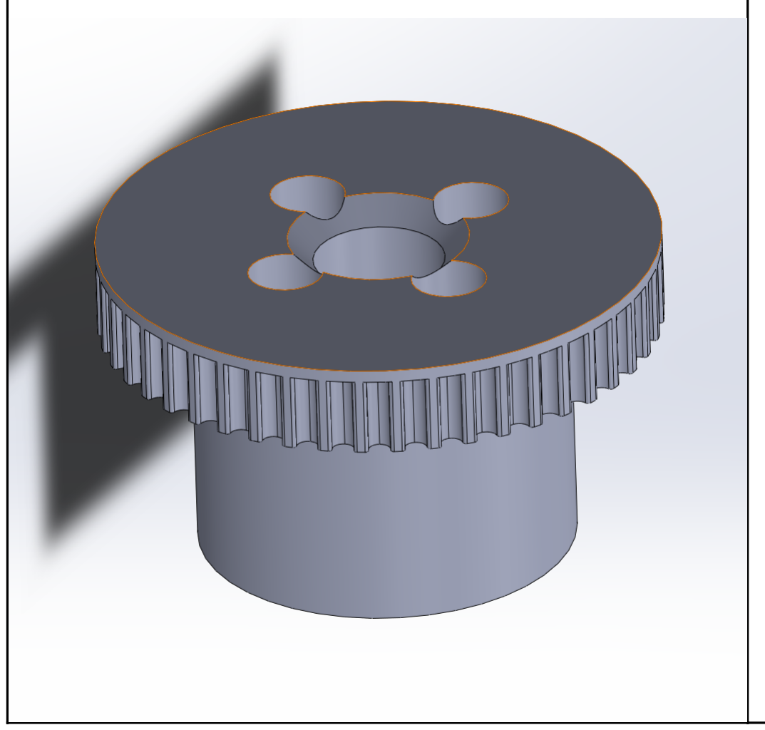
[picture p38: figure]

| Wrist pulley | 19.8 | honey | 50 | 0.15 | 6 | 5 | 3

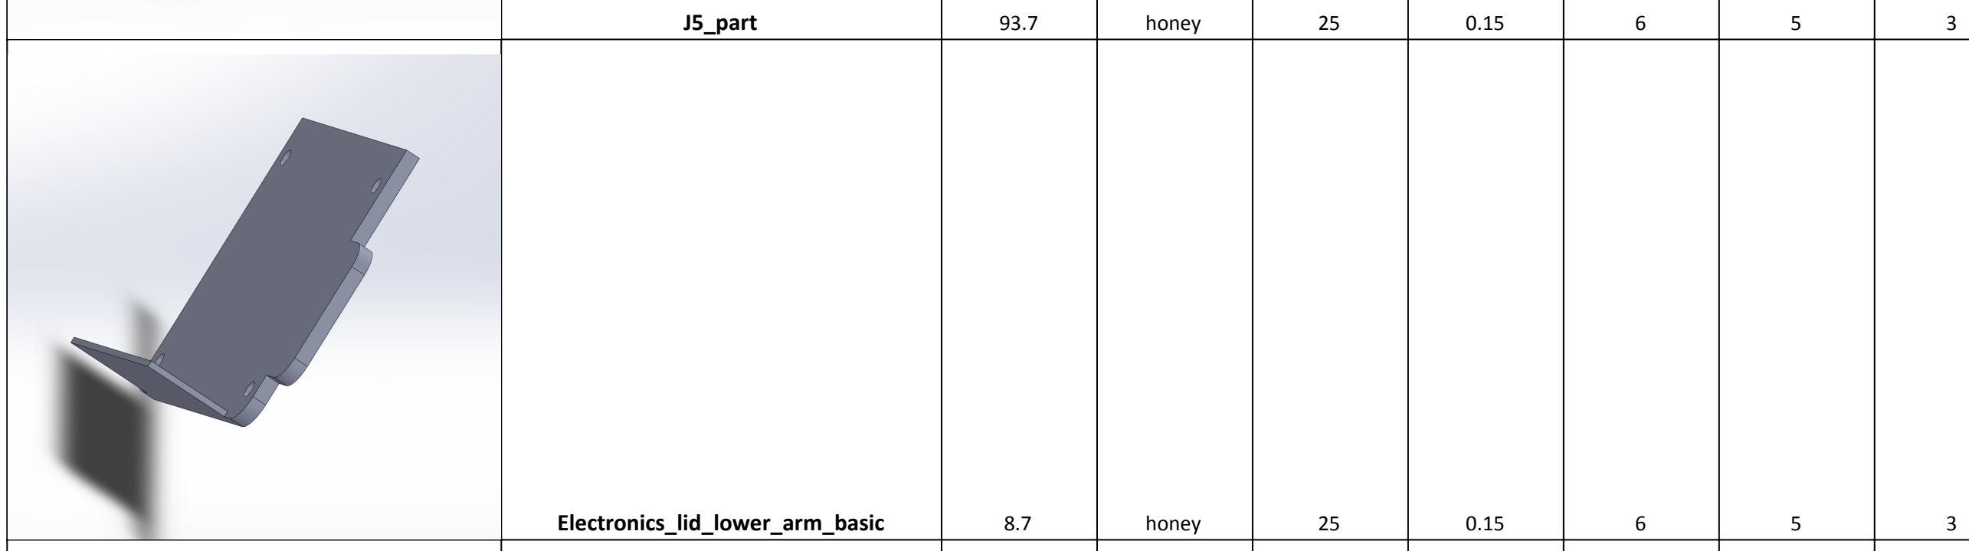
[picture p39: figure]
J5_part; honey; Electronics_lid_lower_arm_basic
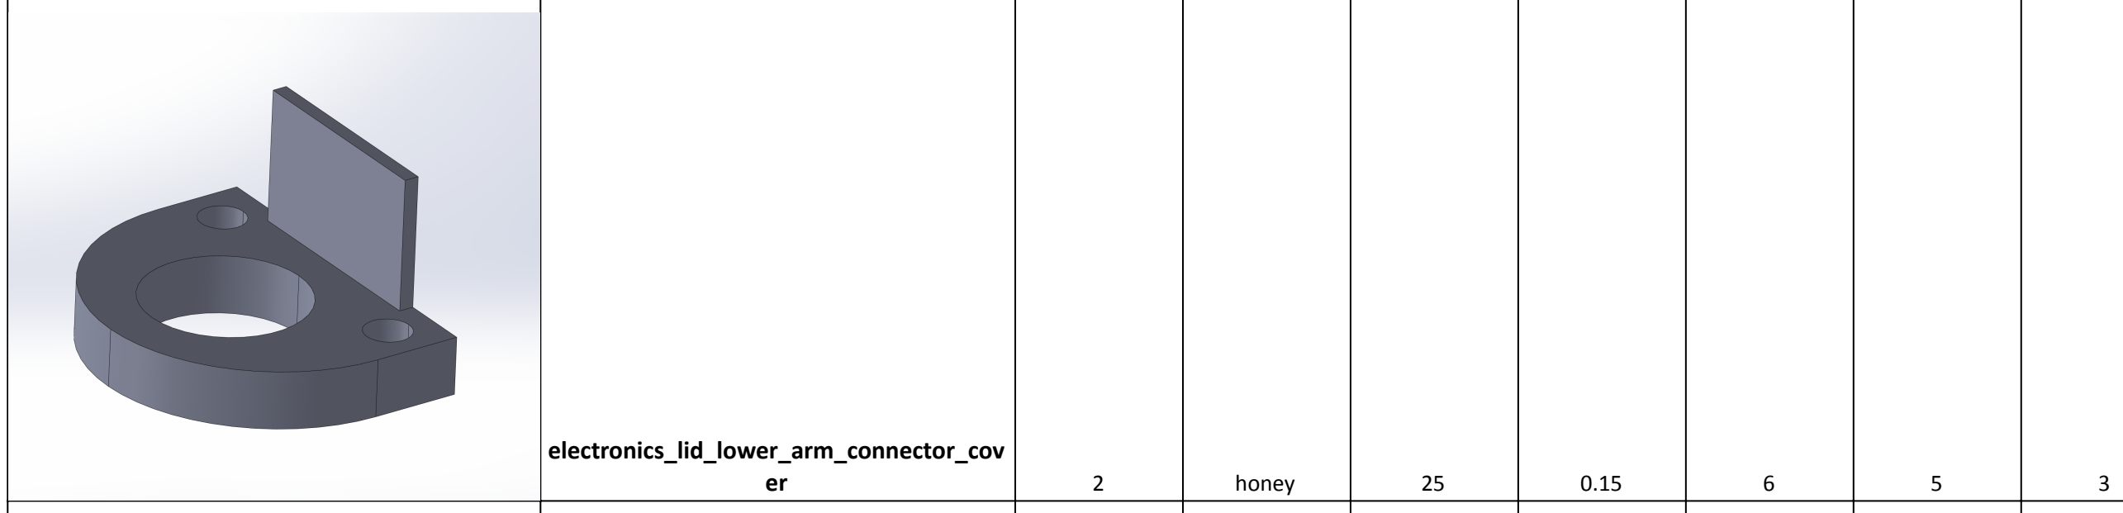
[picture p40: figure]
electronics_lid_lower_arm_connector_cov er; honey
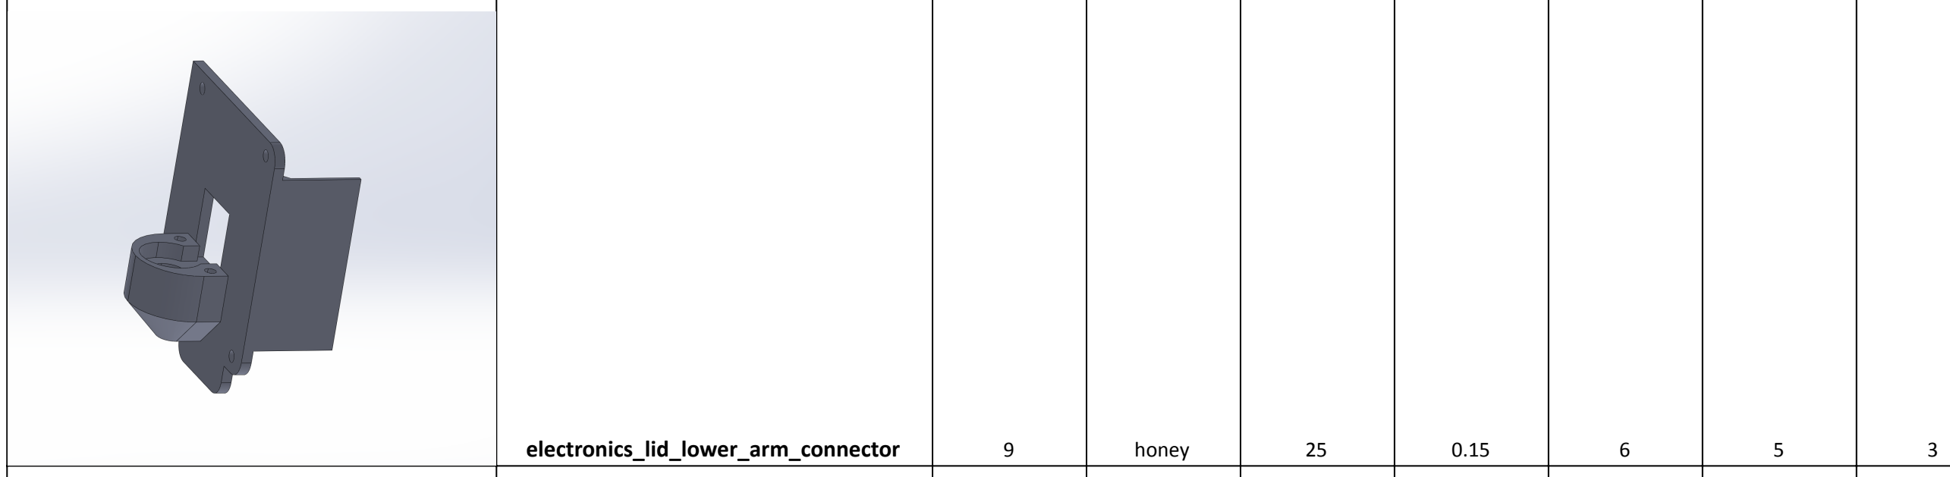
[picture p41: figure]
electronics_lid_lower_arm_connector; honey
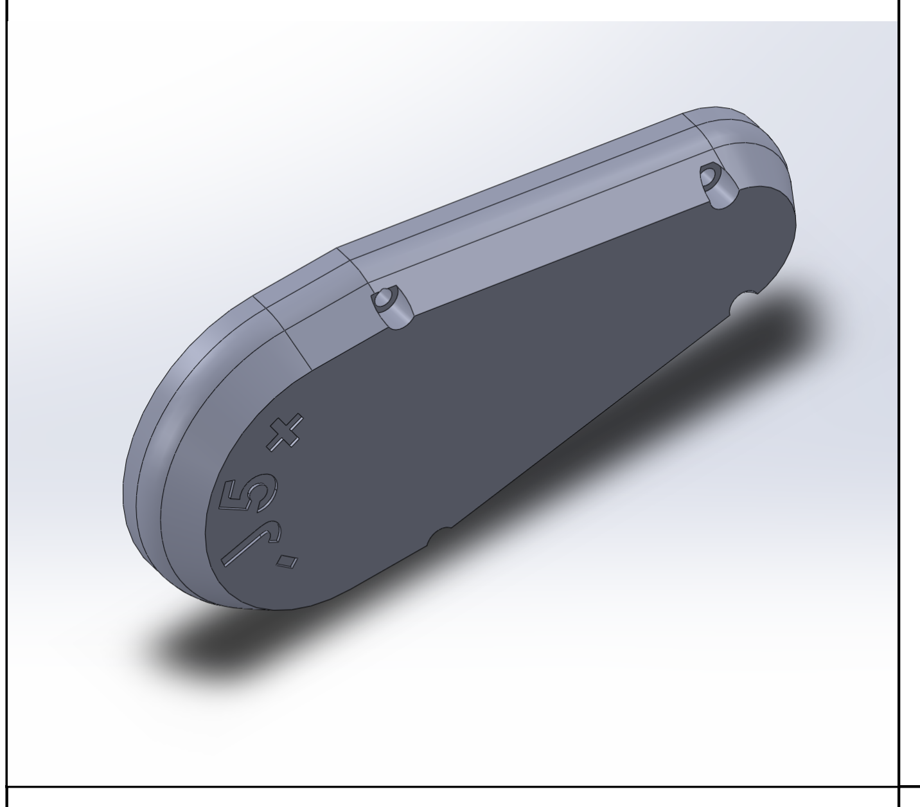
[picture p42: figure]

J5_belt_lid | 17.6 | honey | 25 | 0.15 | 6 | 5 | 3

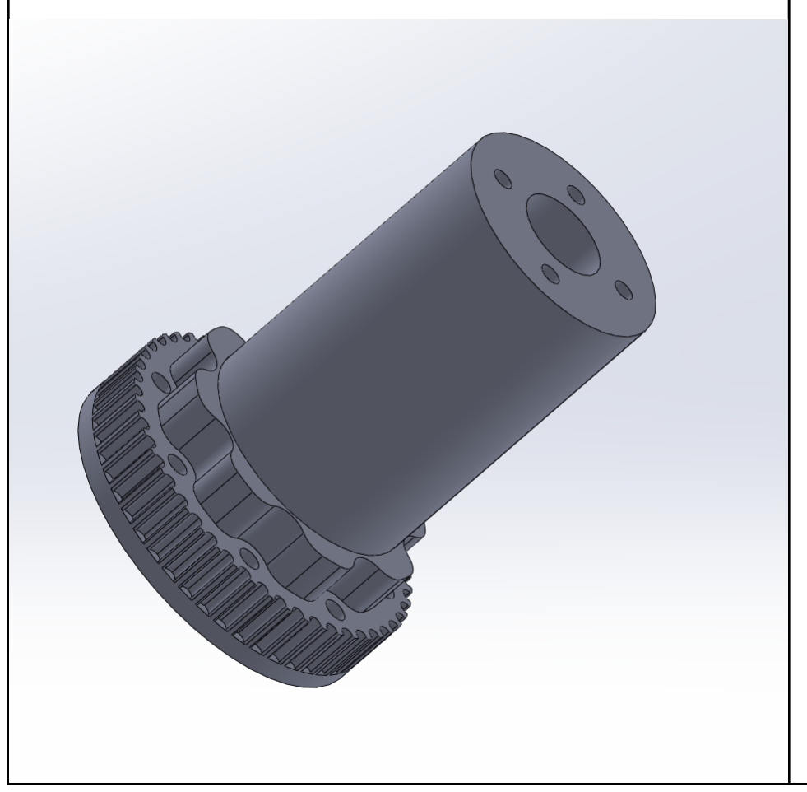
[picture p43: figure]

J4_output_pulley | 40.7 | honey | 50 | 0.15 | 6 | 5 | 3

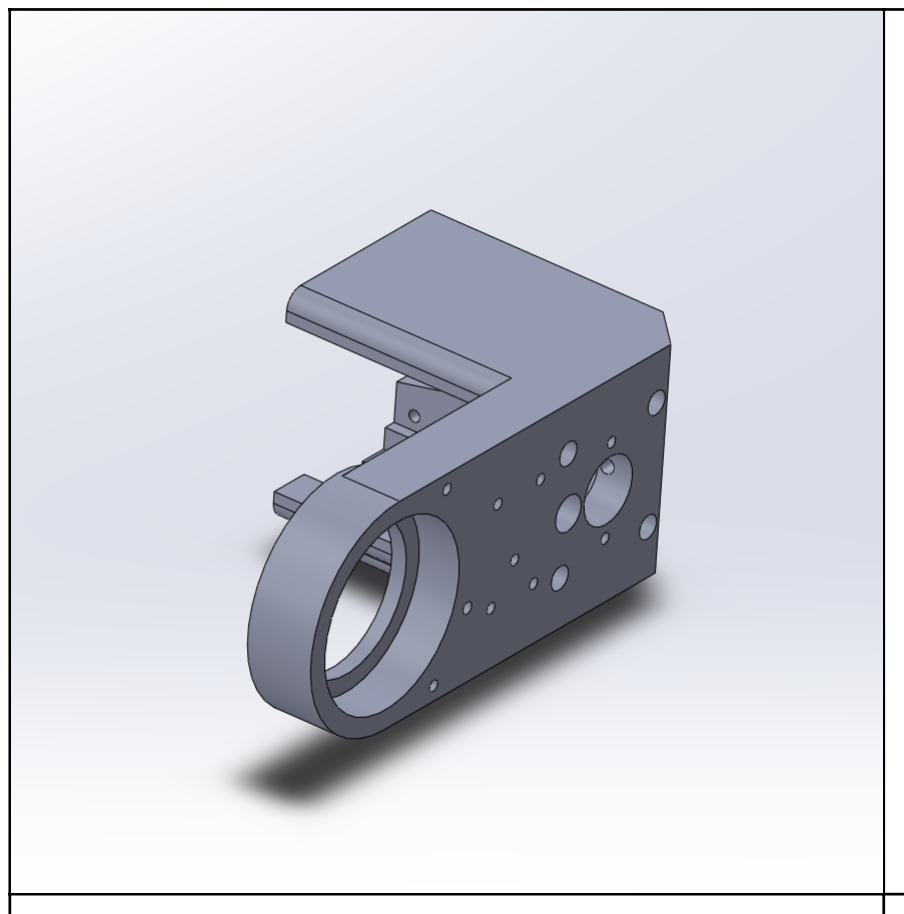
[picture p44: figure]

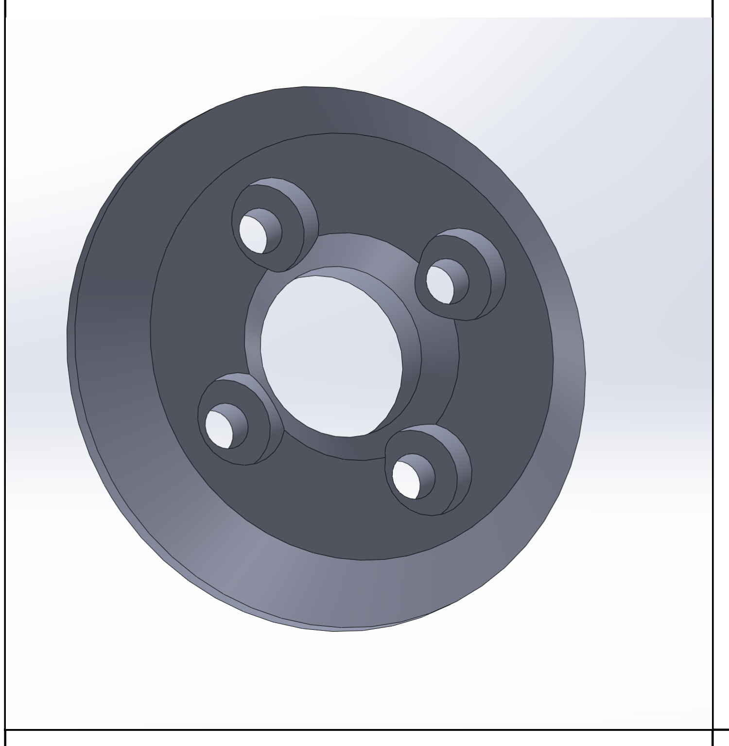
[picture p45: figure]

J4_bearing_backplate | 4 | honey | 25 | 0.15 | 6 | 5 | 3

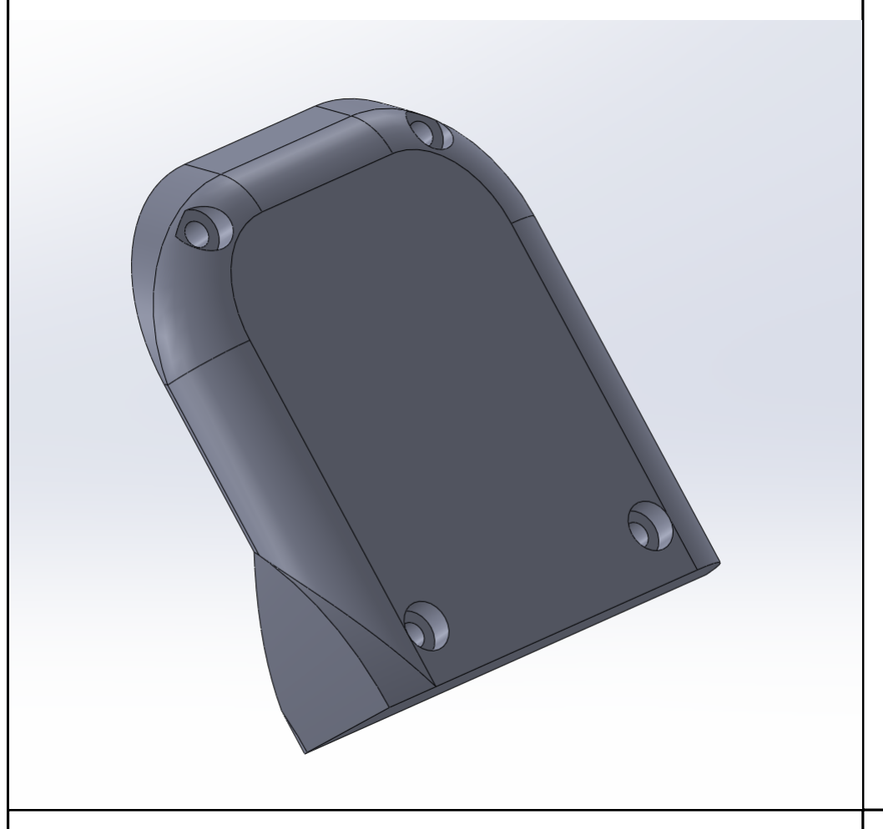
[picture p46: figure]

Elbow_lid | 19.7 | honey | 25 | 0.15 | 6 | 5 | 3

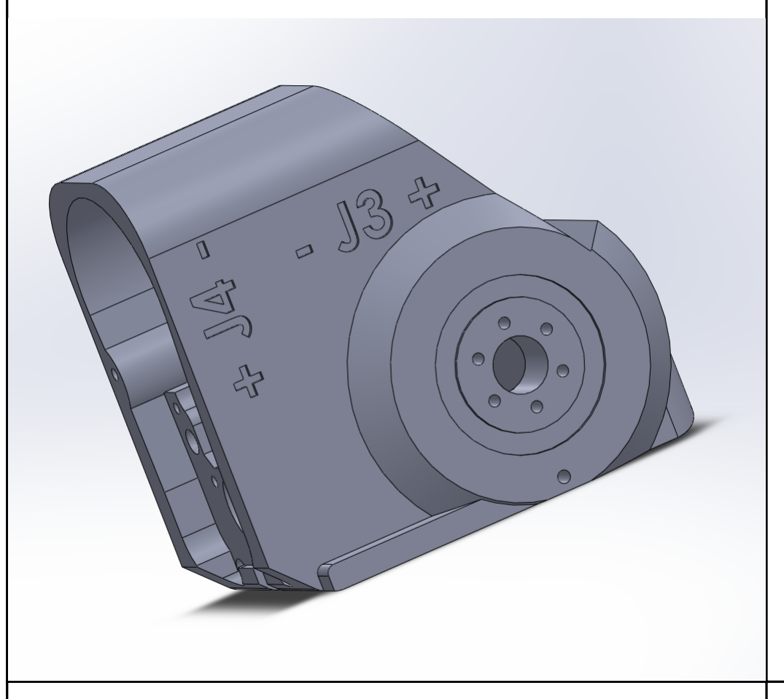
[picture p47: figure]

Elbow_part | 172.8 | honey | 25 | 0.15 | 6 | 5 | 3

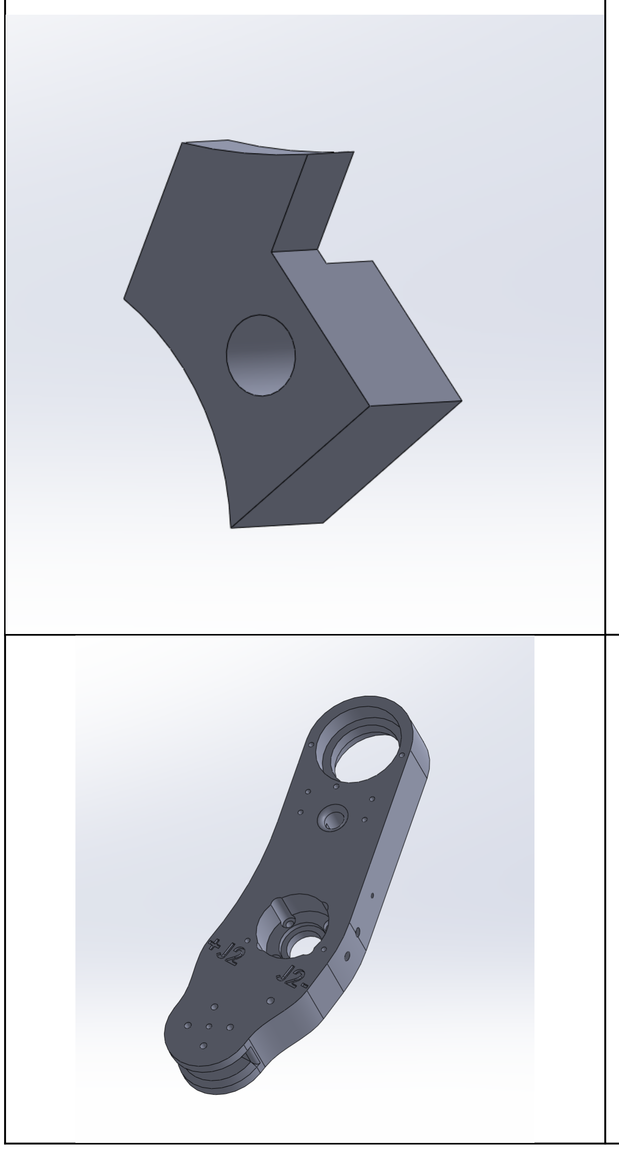
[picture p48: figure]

J4_limiter | 1 | honey | 25 | 0.15 | 6 | 5 | 3
upper_arm | 192.6 | honey | 35 | 0.15 | 6 | 5 | 3

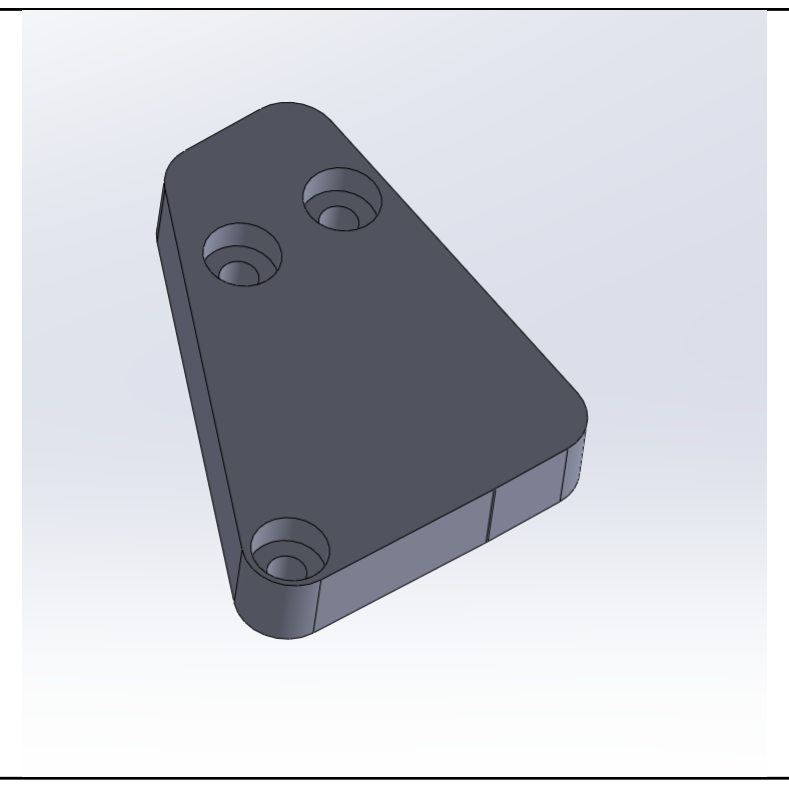
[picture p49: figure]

Elbow_blocker | 4.8 | honey | 25 | 0.15 | 6 | 5 | 3

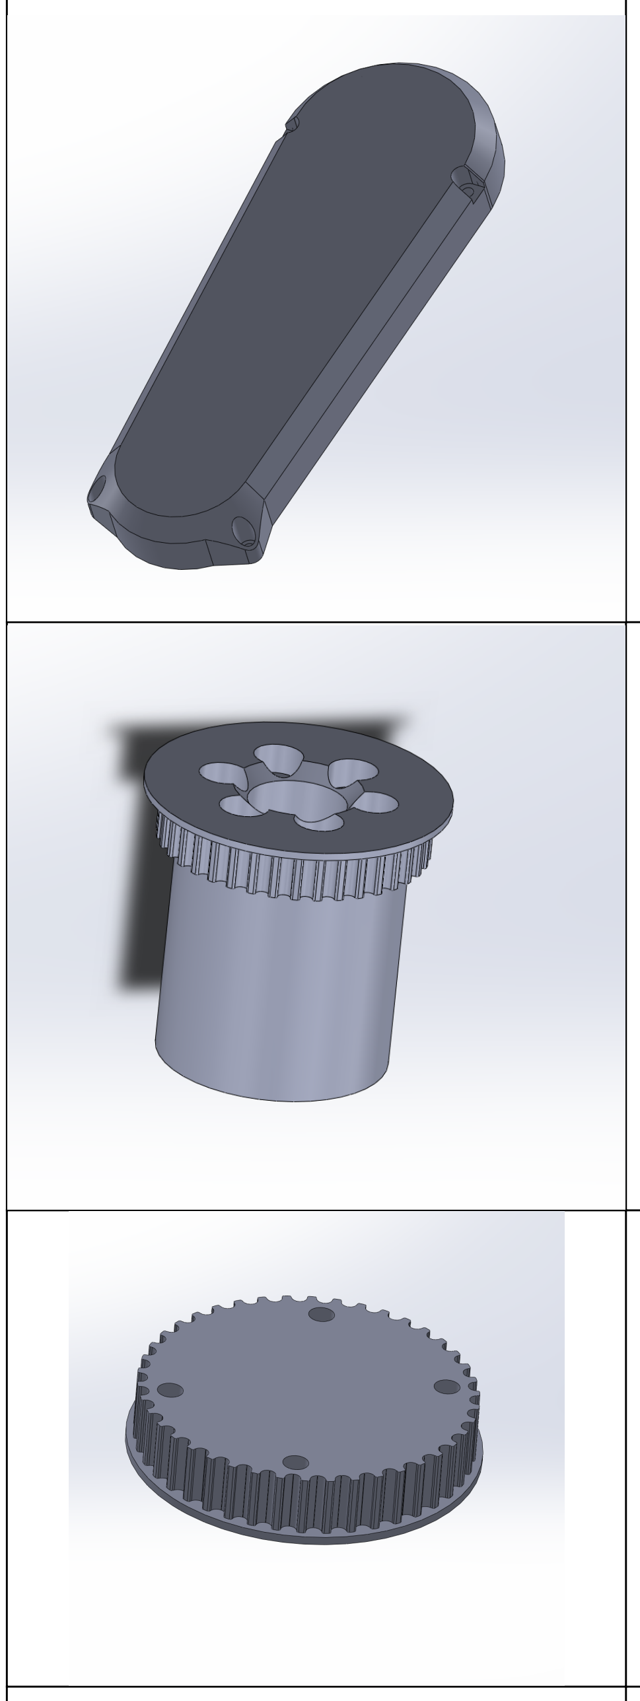
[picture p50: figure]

Upper_arm_cover | 26 | honey | 25 | 0.15 | 6 | 5 | 3
Upper_arm_pulley_38t | 22.3 | honey | 50 | 0.15 | 6 | 5 | 3
42_pulley | 8.5 | honey | 50 | 0.15 | 6 | 5 | 3

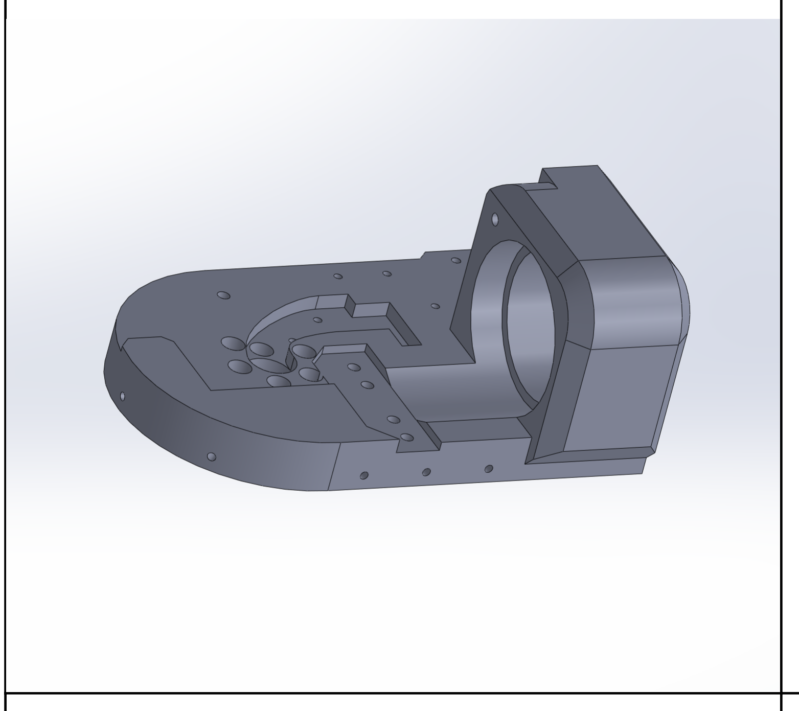
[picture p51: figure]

Turret | 179.1 | honey | 25 | 0.15 | 6 | 5 | 3

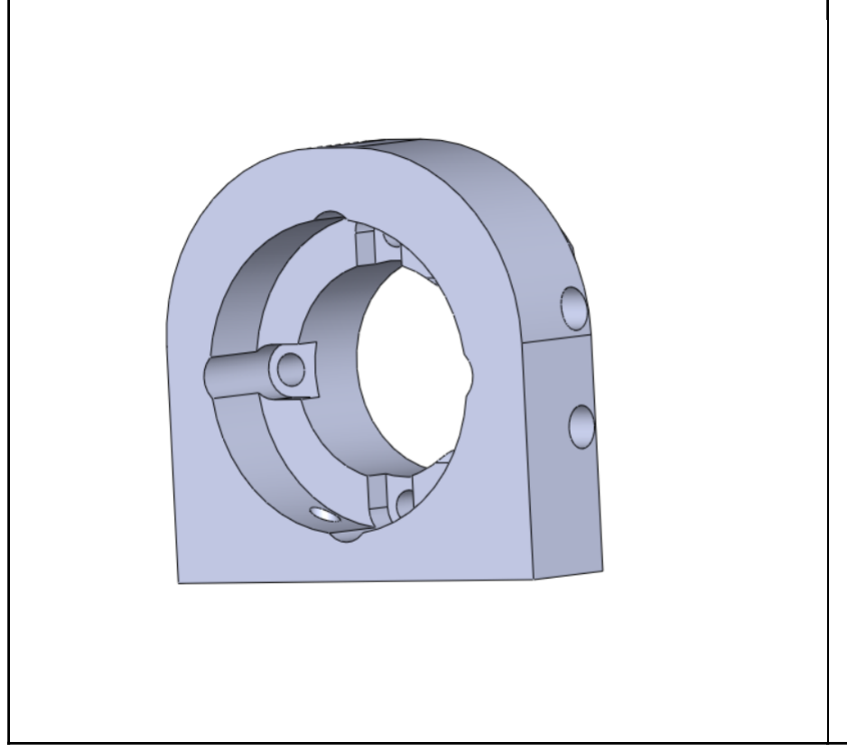
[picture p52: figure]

J2_turret_motor_holder | 33.8 | honey | 50 | 0.15 | 6 | 5 | 3

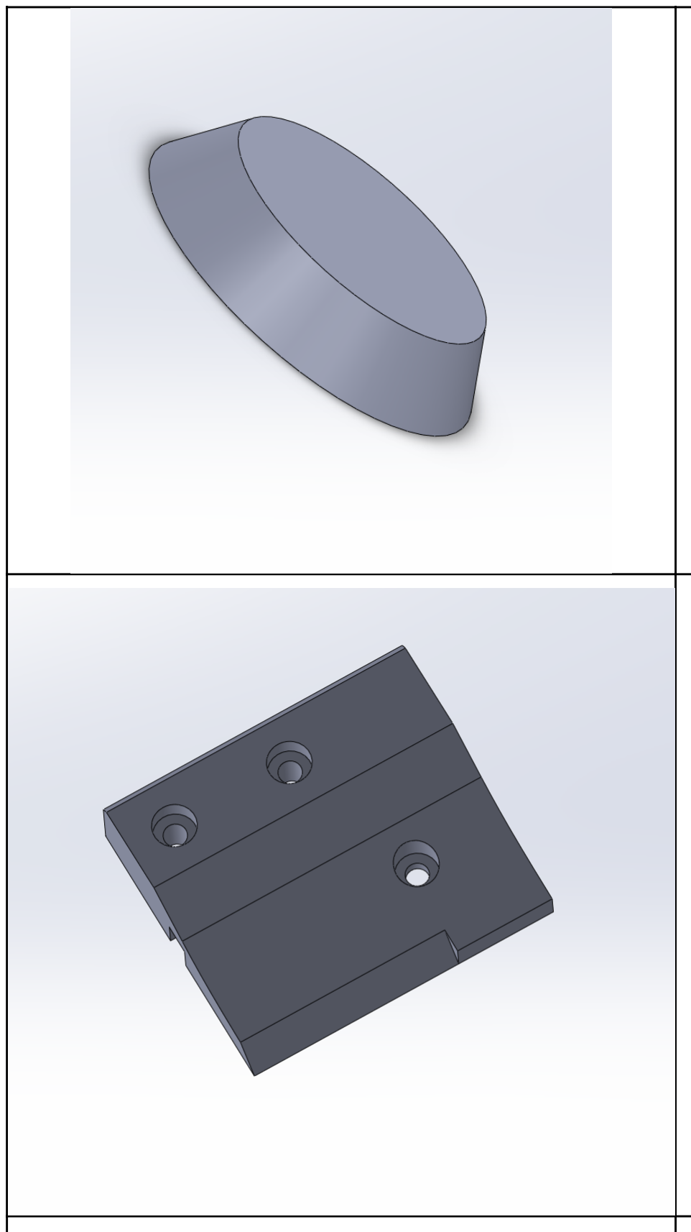
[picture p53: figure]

J2_cover | 11.1 | honey | 25 | 0.15 | 6 | 5 | 3
J2_blocker | 9.4 | honey | 25 | 0.15 | 6 | 5 | 3

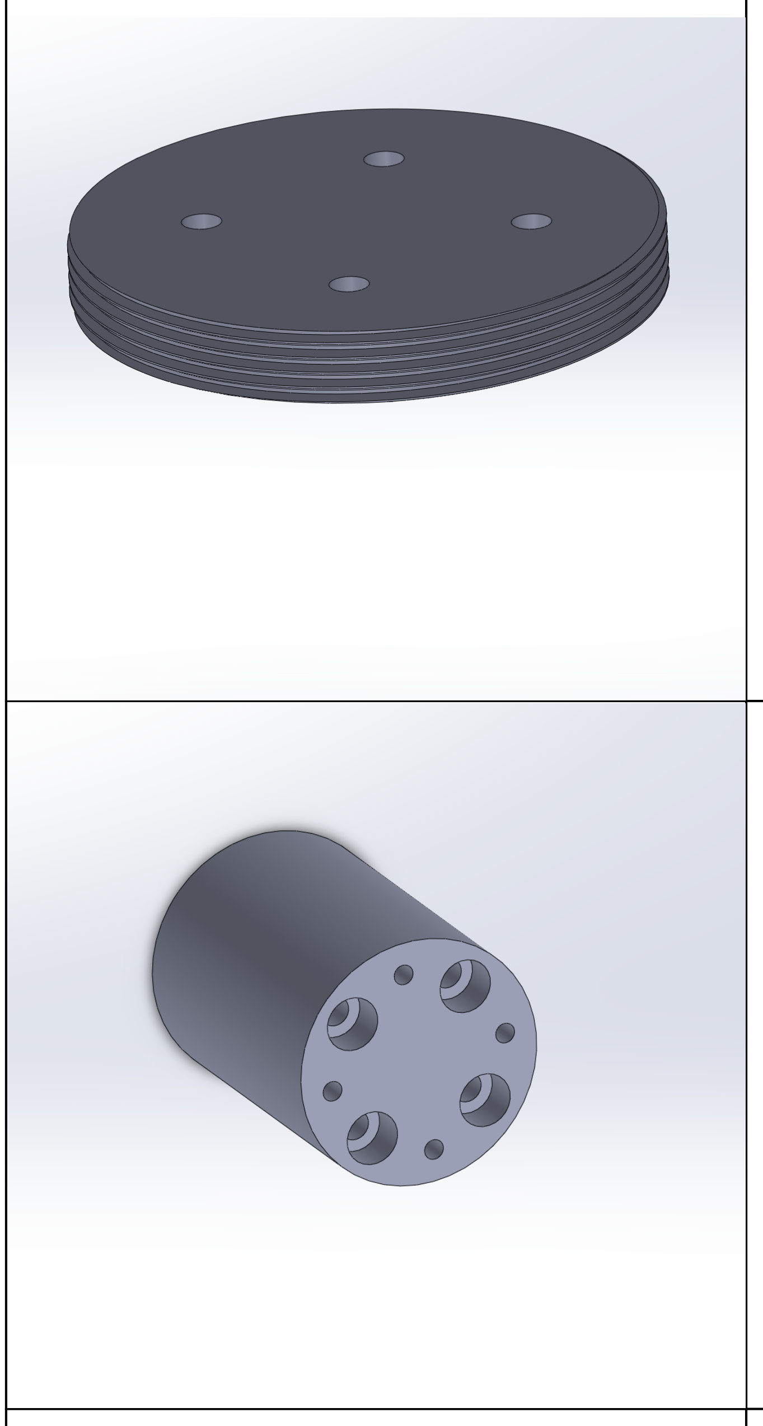
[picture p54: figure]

J2_bearing_backplate | 7 | honey | 25 | 0.15 | 6 | 5 | 3
J2_shaft | 37.4 | honey | 50 | 0.15 | 6 | 5 | 3

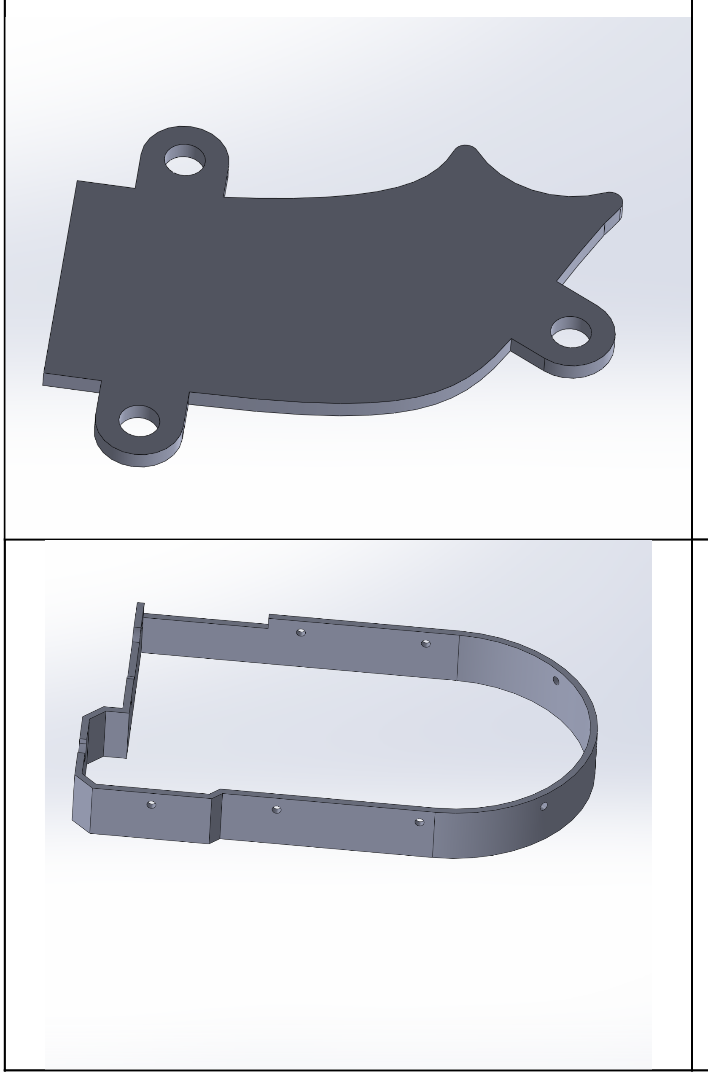
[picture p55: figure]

Turret_wire_cover | 1.7 | honey | 25 | 0.15 | 6 | 5 | 3
Turret_cover | 29 | honey | 25 | 0.15 | 6 | 5 | 3

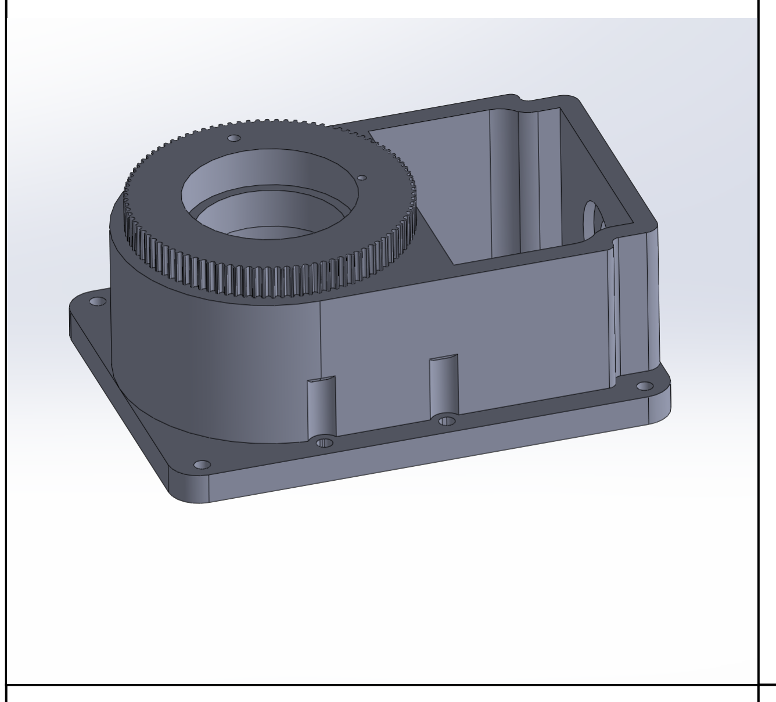
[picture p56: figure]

Base | 317 | honey | 25 | 0.15 | 6 | 5 | 3

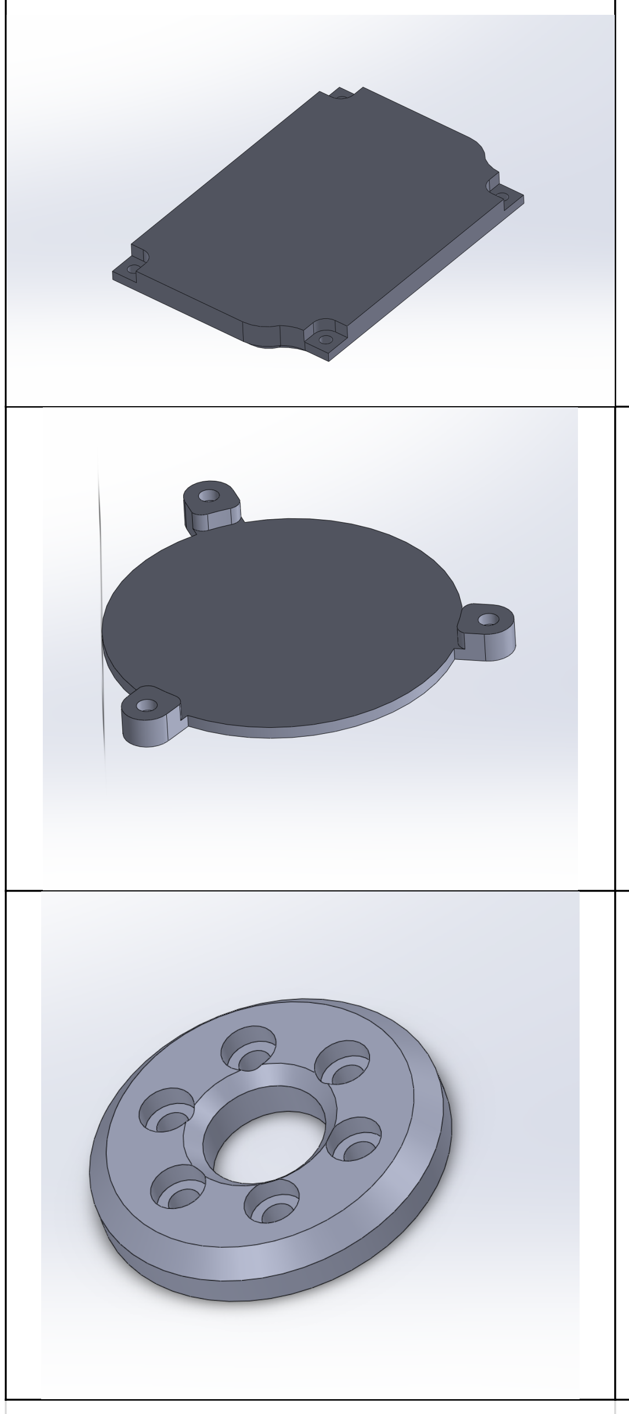
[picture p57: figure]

Base_lid_electronics | 35 | honey | 25 | 0.15 | 6 | 5 | 3
J1_bottom_lid | 6.1 | honey | 25 | 0.15 | 6 | 5 | 3
Base_bearing_backplate | 7.2 | honey | 25 | 0.15 | 6 | 5 | 3

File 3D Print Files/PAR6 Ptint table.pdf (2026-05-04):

We used a Prusa MK4 with the default Prusament PETG filament profile. To ensure your PAR6 robot functions properly, please try to match these print settings on your own printer. While the mass doesn't need to be exact for every part, you should aim for the values listed in the table once your model is sliced. Note: Make sure to deduct the mass of any support

### material! Mass in the table is for the parts without any support material!


IMG | Part name | mass (g) | Infill type | Infill % | Layer h | Top layers | Bot layers | Perimeters
| Wrist | 70 | honey | 25 | 0.15 | 6 | 5 | 3


| Wrist lid | 8.3 | honey | 25 | 0.15 | 6 | 5 | 3


| Wrist pulley | 19.8 | honey | 50 | 0.15 | 6 | 5 | 3

J5_part; honey; Electronics_lid_lower_arm_basic
electronics_lid_lower_arm_connector_cov er; honey
electronics_lid_lower_arm_connector; honey

J5_belt_lid | 17.6 | honey | 25 | 0.15 | 6 | 5 | 3


J4_output_pulley | 40.7 | honey | 50 | 0.15 | 6 | 5 | 3



J4_bearing_backplate | 4 | honey | 25 | 0.15 | 6 | 5 | 3


Elbow_lid | 19.7 | honey | 25 | 0.15 | 6 | 5 | 3


Elbow_part | 172.8 | honey | 25 | 0.15 | 6 | 5 | 3


J4_limiter | 1 | honey | 25 | 0.15 | 6 | 5 | 3
upper_arm | 192.6 | honey | 35 | 0.15 | 6 | 5 | 3


Elbow_blocker | 4.8 | honey | 25 | 0.15 | 6 | 5 | 3


Upper_arm_cover | 26 | honey | 25 | 0.15 | 6 | 5 | 3
Upper_arm_pulley_38t | 22.3 | honey | 50 | 0.15 | 6 | 5 | 3
42_pulley | 8.5 | honey | 50 | 0.15 | 6 | 5 | 3


Turret | 179.1 | honey | 25 | 0.15 | 6 | 5 | 3


J2_turret_motor_holder | 33.8 | honey | 50 | 0.15 | 6 | 5 | 3


J2_cover | 11.1 | honey | 25 | 0.15 | 6 | 5 | 3
J2_blocker | 9.4 | honey | 25 | 0.15 | 6 | 5 | 3


J2_bearing_backplate | 7 | honey | 25 | 0.15 | 6 | 5 | 3
J2_shaft | 37.4 | honey | 50 | 0.15 | 6 | 5 | 3


Turret_wire_cover | 1.7 | honey | 25 | 0.15 | 6 | 5 | 3
Turret_cover | 29 | honey | 25 | 0.15 | 6 | 5 | 3


Base | 317 | honey | 25 | 0.15 | 6 | 5 | 3

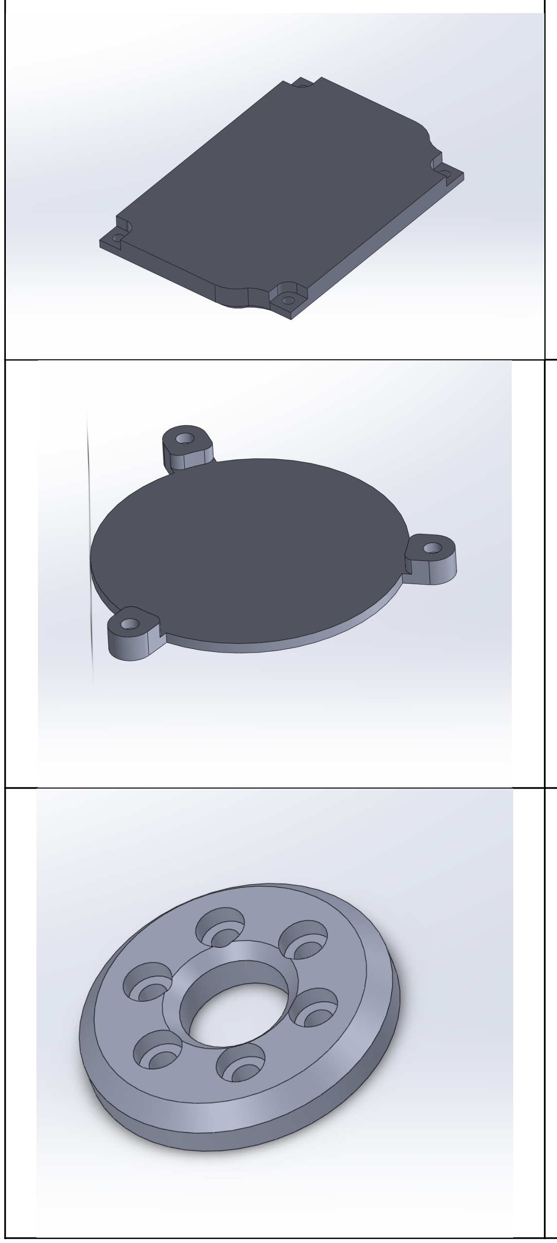
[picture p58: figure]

Base_lid_electronics | 35 | honey | 25 | 0.15 | 6 | 5 | 3
J1_bottom_lid | 6.1 | honey | 25 | 0.15 | 6 | 5 | 3
Base_bearing_backplate | 7.2 | honey | 25 | 0.15 | 6 | 5 | 3

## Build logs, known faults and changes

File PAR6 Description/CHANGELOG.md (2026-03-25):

# Changelog – Source Robotics PAR6 Description

All notable changes to this model will be documented in this file.

## [10-2-2025]
- Added the initial files:
    - MJCF for PAR6 with SSG48 and MSG grippers
    - URDF files for 3 versions: PAR6 with flange, SSG48 gripper and MSG gripper
    - Added extra jaw options for SSG48 gripper

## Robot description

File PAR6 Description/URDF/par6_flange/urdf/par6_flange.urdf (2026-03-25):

<?xml version="1.0" encoding="utf-8"?>
<!-- This URDF was automatically created by SolidWorks to URDF Exporter! Originally created by Stephen Brawner (brawner@gmail.com) 
     Commit Version: 1.6.0-4-g7f85cfe  Build Version: 1.6.7995.38578
     For more information, please see http://wiki.ros.org/sw_urdf_exporter -->
<robot name="par6_flange">
  <link name="base_link">
    <inertial>
      <origin xyz="-0.03291842362796 -3.9760226777652E-09 0.0314011608034117" rpy="0 0 0" />
      <mass value="0.998265338800333" />
      <inertia ixx="0.00118949401625524" ixy="-3.53594527704034E-12" ixz="-5.94924049151936E-05" iyy="0.00238159101024826" iyz="-6.16822652141328E-11" izz="0.00282485466366564" />
    </inertial>
    <visual>
      <origin xyz="0 0 0" rpy="0 0 0" />
      <geometry>
        <mesh filename="package://par6_flange/meshes/base_link.STL" />
      </geometry>
      <material name="">
        <color rgba="0.792156862745098 0.819607843137255 0.933333333333333 1" />
      </material>
    </visual>
    <collision>
      <origin xyz="0 0 0" rpy="0 0 0" />
      <geometry>
        <mesh filename="package://par6_flange/meshes/base_link.STL" />
      </geometry>
    </collision>
  </link>
  <link name="shoulder">
    <inertial>
      <origin xyz="0.00656811939881225 0.029093538967332 0.099551347543143" rpy="0 0 0" />
      <mass value="0.620900499130961" />
      <inertia ixx="0.00100663738746705" ixy="-6.26580888440265E-05" ixz="-5.94906456216179E-05" iyy="0.000546947368013689" iyz="-0.000133114961306643" izz="0.00119083362934585" />
    </inertial>
    <visual>
      <origin xyz="0 0 0" rpy="0 0 0" />
      <geometry>
        <mesh filename="package://par6_flange/meshes/shoulder.STL" />
      </geometry>
      <material name="">
        <color rgba="0.792156862745098 0.819607843137255 0.933333333333333 1" />
      </material>
    </visual>
    <collision>
      <origin xyz="0 0 0" rpy="0 0 0" />
      <geometry>
        <mesh filename="package://par6_flange/meshes/shoulder.STL" />
      </geometry>
    </collision>
  </link>
  <joint name="shoulder_JOINT" type="revolute">
    <origin xyz="0 0 0" rpy="0 0 0" />
    <parent link="base_link" />
    <child link="shoulder" />
    <axis xyz="0 0 -1" />
    <limit lower="0" upper="0" effort="0" velocity="0" />
  </joint>
  <link name="upper_arm">
    <inertial>
      <origin xyz="-0.00854934366236464 -0.071342142449425 0.0416391335881913" rpy="0 0 0" />
      <mass value="0.564255649327409" />
      <inertia ixx="0.00161401505877108" ixy="-2.37624134871021E-05" ixz="-1.23771305810394E-05" iyy="0.000283296701166046" iyz="-0.000134635985563592" izz="0.00163917151493148" />
    </inertial>
    <visual>
      <origin xyz="0 0 0" rpy="0 0 0" />
      <geometry>
        <mesh filename="package://par6_flange/meshes/upper_arm.STL" />
      </geometry>
      <material name="">
        <color rgba="0.792156862745098 0.819607843137255 0.933333333333333 1" />
      </material>
    </visual>
    <collision>
      <origin xyz="0 0 0" rpy="0 0 0" />
      <geometry>
        <mesh filename="package://par6_flange/meshes/upper_arm.STL" />
      </geometry>
    </collision>
  </link>
  <joint name="upper_arm_JOINT" type="revolute">
    <origin xyz="0.0234207210610365 0 0.1105" rpy="-1.5707963267949 0 0" />
    <parent link="shoulder" />
    <child link="upper_arm" />
    <axis xyz="0 0 1" />
    <limit lower="0" upper="0" effort="0" velocity="0" />
  </joint>
  <link name="elbow">
    <inertial>
      <origin xyz="0.0155509885239581 -0.0191127686426632 -0.00153322577917242" rpy="0 0 0" />
      <mass value="0.550970997806044" />
      <inertia ixx="0.00057827573271994" ixy="0.000116505232322314" ixz="-1.19955293256511E-05" iyy="0.0005670116769447" iyz="1.5581425503602E-05" izz="0.000815862001506842" />
    </inertial>
    <visual>
      <origin xyz="0 0 0" rpy="0 0 0" />
      <geometry>
        <mesh filename="package://par6_flange/meshes/elbow.STL" />
      </geometry>
      <material name="">
        <color rgba="0.792156862745098 0.819607843137255 0.933333333333333 1" />
      </material>
    </visual>
    <collision>
      <origin xyz="0 0 0" rpy="0 0 0" />
      <geometry>
        <mesh filename="package://par6_flange/meshes/elbow.STL" />
      </geometry>
    </collision>
  </link>
  <joint name="elbow_JOINT" type="revolute">
    <origin xyz="0 -0.18 0" rpy="3.14159265358979 0 -1.5707963267949" />
    <parent link="upper_arm" />
    <child link="elbow" />
    <axis xyz="0 0 -1" />
    <limit lower="0" upper="0" effort="0" velocity="0" />
  </joint>
  <link name="lower_arm">
    <inertial>
      <origin xyz="0.00052733545462913 -0.0101658497051341 -0.0925926618710992" rpy="0 0 0" />
      <mass value="0.382768168076153" />
      <inertia ixx="0.000383809752758758" ixy="-5.71777005742453E-06" ixz="-1.13435862343092E-06" iyy="0.000324613577491975" iyz="-6.48194702731559E-05" izz="0.000252488975982478" />
    </inertial>
    <visual>
      <origin xyz="0 0 0" rpy="0 0 0" />
      <geometry>
        <mesh filename="package://par6_flange/meshes/lower_arm.STL" />
      </geometry>
      <material name="">
        <color rgba="0.792156862745098 0.819607843137255 0.933333333333333 1" />
      </material>
    </visual>
    <collision>
      <origin xyz="0 0 0" rpy="0 0 0" />
      <geometry>
        <mesh filename="package://par6_flange/meshes/lower_arm.STL" />
      </geometry>
    </collision>
  </link>
  <joint name="lower_arm_JOINT" type="revolute">
    <origin xyz="0.0434999999999984 0 0" rpy="1.5707963267949 0 -3.14159265358979" />
    <parent link="elbow" />
    <child link="lower_arm" />
    <axis xyz="0 0 -1" />
    <limit lower="0" upper="0" effort="0" velocity="0" />
  </joint>
  <link name="wrist">
    <inertial>
      <origin xyz="-1.54606600299978E-06 -0.00314847566621396 0.000193929742576593" rpy="0 0 0" />
      <mass value="0.230864625594321" />
      <inertia ixx="0.00018082969543415" ixy="-4.63392548734812E-10" ixz="-6.79284338617314E-09" iyy="0.000106212288444716" iyz="2.87958450952461E-06" izz="0.000175598200731164" />
    </inertial>
    <visual>
      <origin xyz="0 0 0" rpy="0 0 0" />
      <geometry>
        <mesh filename="package://par6_flange/meshes/wrist.STL" />
      </geometry>
      <material name="">
        <color rgba="0.792156862745098 0.819607843137255 0.933333333333333 1" />
      </material>
    </visual>
    <collision>
      <origin xyz="0 0 0" rpy="0 0 0" />
      <geometry>
        <mesh filename="package://par6_flange/meshes/wrist.STL" />
      </geometry>
    </collision>
  </link>
  <joint name="wrist_JOINT" type="revolute">
    <origin xyz="0 0 -0.177000000000002" rpy="-1.57079632679489 0 0" />
    <parent link="lower_arm" />
    <child link="wrist" />
    <axis xyz="0 0 1" />
    <limit lower="0" upper="0" effort="0" velocity="0" />
  </joint>
  <link name="gripper">
    <inertial>
      <origin xyz="-6.28287090892465E-05 6.96476392843537E-05 -0.0490534784184994" rpy="0 0 0" />
      <mass value="0.024635742513522" />
      <inertia ixx="5.90242323471309E-06" ixy="2.35508451621105E-08" ixz="1.84095312865299E-08" iyy="6.06157538333085E-06" iyz="9.37735630145885E-10" izz="1.10660922067779E-05" />
    </inertial>
    <visual>
      <origin xyz="0 0 0" rpy="0 0 0" />
      <geometry>
        <mesh filename="package://par6_flange/meshes/gripper.STL" />
      </geometry>
      <material name="">
        <color rgba="0.792156862745098 0.819607843137255 0.933333333333333 1" />
      </material>
    </visual>
    <collision>
      <origin xyz="0 0 0" rpy="0 0 0" />
      <geometry>
        <mesh filename="package://par6_flange/meshes/gripper.STL" />
      </geometry>
    </collision>
  </link>
  <joint name="gripper_JOINT" type="revolute">
    <origin xyz="0 0 0" rpy="1.5707963267949 0 0" />
    <parent link="wrist" />
    <child link="gripper" />
    <axis xyz="0 0 -1" />
    <limit lower="0" upper="0" effort="0" velocity="0" />
  </joint>
</robot>

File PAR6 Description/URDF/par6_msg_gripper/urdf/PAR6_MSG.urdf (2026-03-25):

<?xml version="1.0" encoding="utf-8"?>
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
<robot name="PAR6_MSG">
  <link name="base_link">
    <inertial>
      <origin xyz="-0.032918423627964 -3.97602362145477E-09 0.0314011608034138" rpy="0 0 0" />
      <mass value="0.998265338800333" />
      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
    </inertial>
    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
  </link>
  <link name="shoulder">
    <inertial>
      <origin xyz="0.00656811939880825 0.0290935389673309 0.099551347543145" rpy="0 0 0" />
      <mass value="0.620900499130961" />
      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
    </inertial>
    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
  </link>
  <joint name="shoulder_JOINT" type="revolute">
    <origin xyz="0 0 0" rpy="0 0 0" />
    <parent link="base_link" />
    <child link="shoulder" />
    <axis xyz="0 0 -1" />
    <limit lower="0" upper="0" effort="0" velocity="0" />
  </joint>
  <link name="upper_arm">
    <inertial>
      <origin xyz="-0.00854934366236779 -0.0713421424494267 0.0416391335881903" rpy="0 0 0" />
      <mass value="0.564255649327409" />
      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
    </inertial>
    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
  </link>
  <joint name="upper_arm_JOINT" type="revolute">
    <origin xyz="0.023421 0 0.1105" rpy="-1.5708 0 0" />
    <parent link="shoulder" />
    <child link="upper_arm" />
    <axis xyz="0 0 1" />
    <limit lower="0" upper="0" effort="0" velocity="0" />
  </joint>
  <link name="elbow">
    <inertial>
      <origin xyz="0.0155509885239591 -0.0191127686426609 -0.00153322577917109" rpy="0 0 0" />
      <mass value="0.550970997806043" />
      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
    </inertial>
    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
  </link>
  <joint name="elbow_JOINT" type="revolute">
    <origin xyz="0 -0.18 0" rpy="3.1416 0 -1.5708" />
    <parent link="upper_arm" />
    <child link="elbow" />
    <axis xyz="0 0 -1" />
    <limit lower="0" upper="0" effort="0" velocity="0" />
  </joint>
  <link name="lower_arm">
    <inertial>
      <origin xyz="0.000527335454629185 -0.0101658497051326 -0.0925926618710919" rpy="0 0 0" />
      <mass value="0.382768168076152" />
      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
    </inertial>
    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
  </link>
  <joint name="lower_arm_JOINT" type="revolute">
    <origin xyz="0.0435 0 0" rpy="1.5708 0 -3.1416" />
    <parent link="elbow" />
    <child link="lower_arm" />
    <axis xyz="0 0 -1" />
    <limit lower="0" upper="0" effort="0" velocity="0" />
  </joint>
  <link name="wrist">
    <inertial>
      <origin xyz="-1.54606600299978E-06 -0.00314847566621398 0.000193929742576537" rpy="0 0 0" />
      <mass value="0.230864625594321" />
      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
    </inertial>
    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
  </link>
  <joint name="wrist_JOINT" type="revolute">
    <origin xyz="0 0 -0.176999999999995" rpy="-1.57079632679489 0 0" />
    <parent link="lower_arm" />
    <child link="wrist" />
    <axis xyz="0 0 1" />
    <limit lower="0" upper="0" effort="0" velocity="0" />
  </joint>
  <link name="gripper">
    <inertial>
      <origin xyz="-0.00642470048892474 0.000282668798476438 -0.0695192335056825" rpy="0 0 0" />
      <mass value="0.167623200457379" />
      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
    </inertial>
    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
  </link>
  <joint name="gripper_JOINT" type="revolute">
    <origin xyz="0 0 0" rpy="1.5708 0 0" />
    <parent link="wrist" />
    <child link="gripper" />
    <axis xyz="0 0 -1" />
    <limit lower="0" upper="0" effort="0" velocity="0" />
  </joint>
  <link name="jaw1">
    <inertial>
      <origin xyz="0.000317390129572659 -0.0636011550113124 -0.0505219142777576" rpy="0 0 0" />
      <mass value="0.0267240448883812" />
      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
    </inertial>
    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
  </link>
  <joint name="joint_jaw1" type="prismatic">
    <origin xyz="0.02835 0 -0.1409" rpy="-3.1416 0 3.1416" />
    <parent link="gripper" />
    <child link="jaw1" />
    <axis xyz="0 -1 0" />
    <limit lower="0" upper="0" effort="0" velocity="0" />
  </joint>
  <link name="jaw2">
    <inertial>
      <origin xyz="0.000313277058697659 0.0636017321420815 -0.0494862901594326" rpy="0 0 0" />
      <mass value="0.0267245850480152" />
      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
    </inertial>
    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
  </link>
  <joint name="joint_jaw2" type="prismatic">
    <mimic joint="joint_jaw1" multiplier="-1" offset="0"/>
    <origin xyz="0.02835 0 -0.1409" rpy="-3.1416 0 3.1416" />
    <parent link="gripper" />
    <child link="jaw2" />
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

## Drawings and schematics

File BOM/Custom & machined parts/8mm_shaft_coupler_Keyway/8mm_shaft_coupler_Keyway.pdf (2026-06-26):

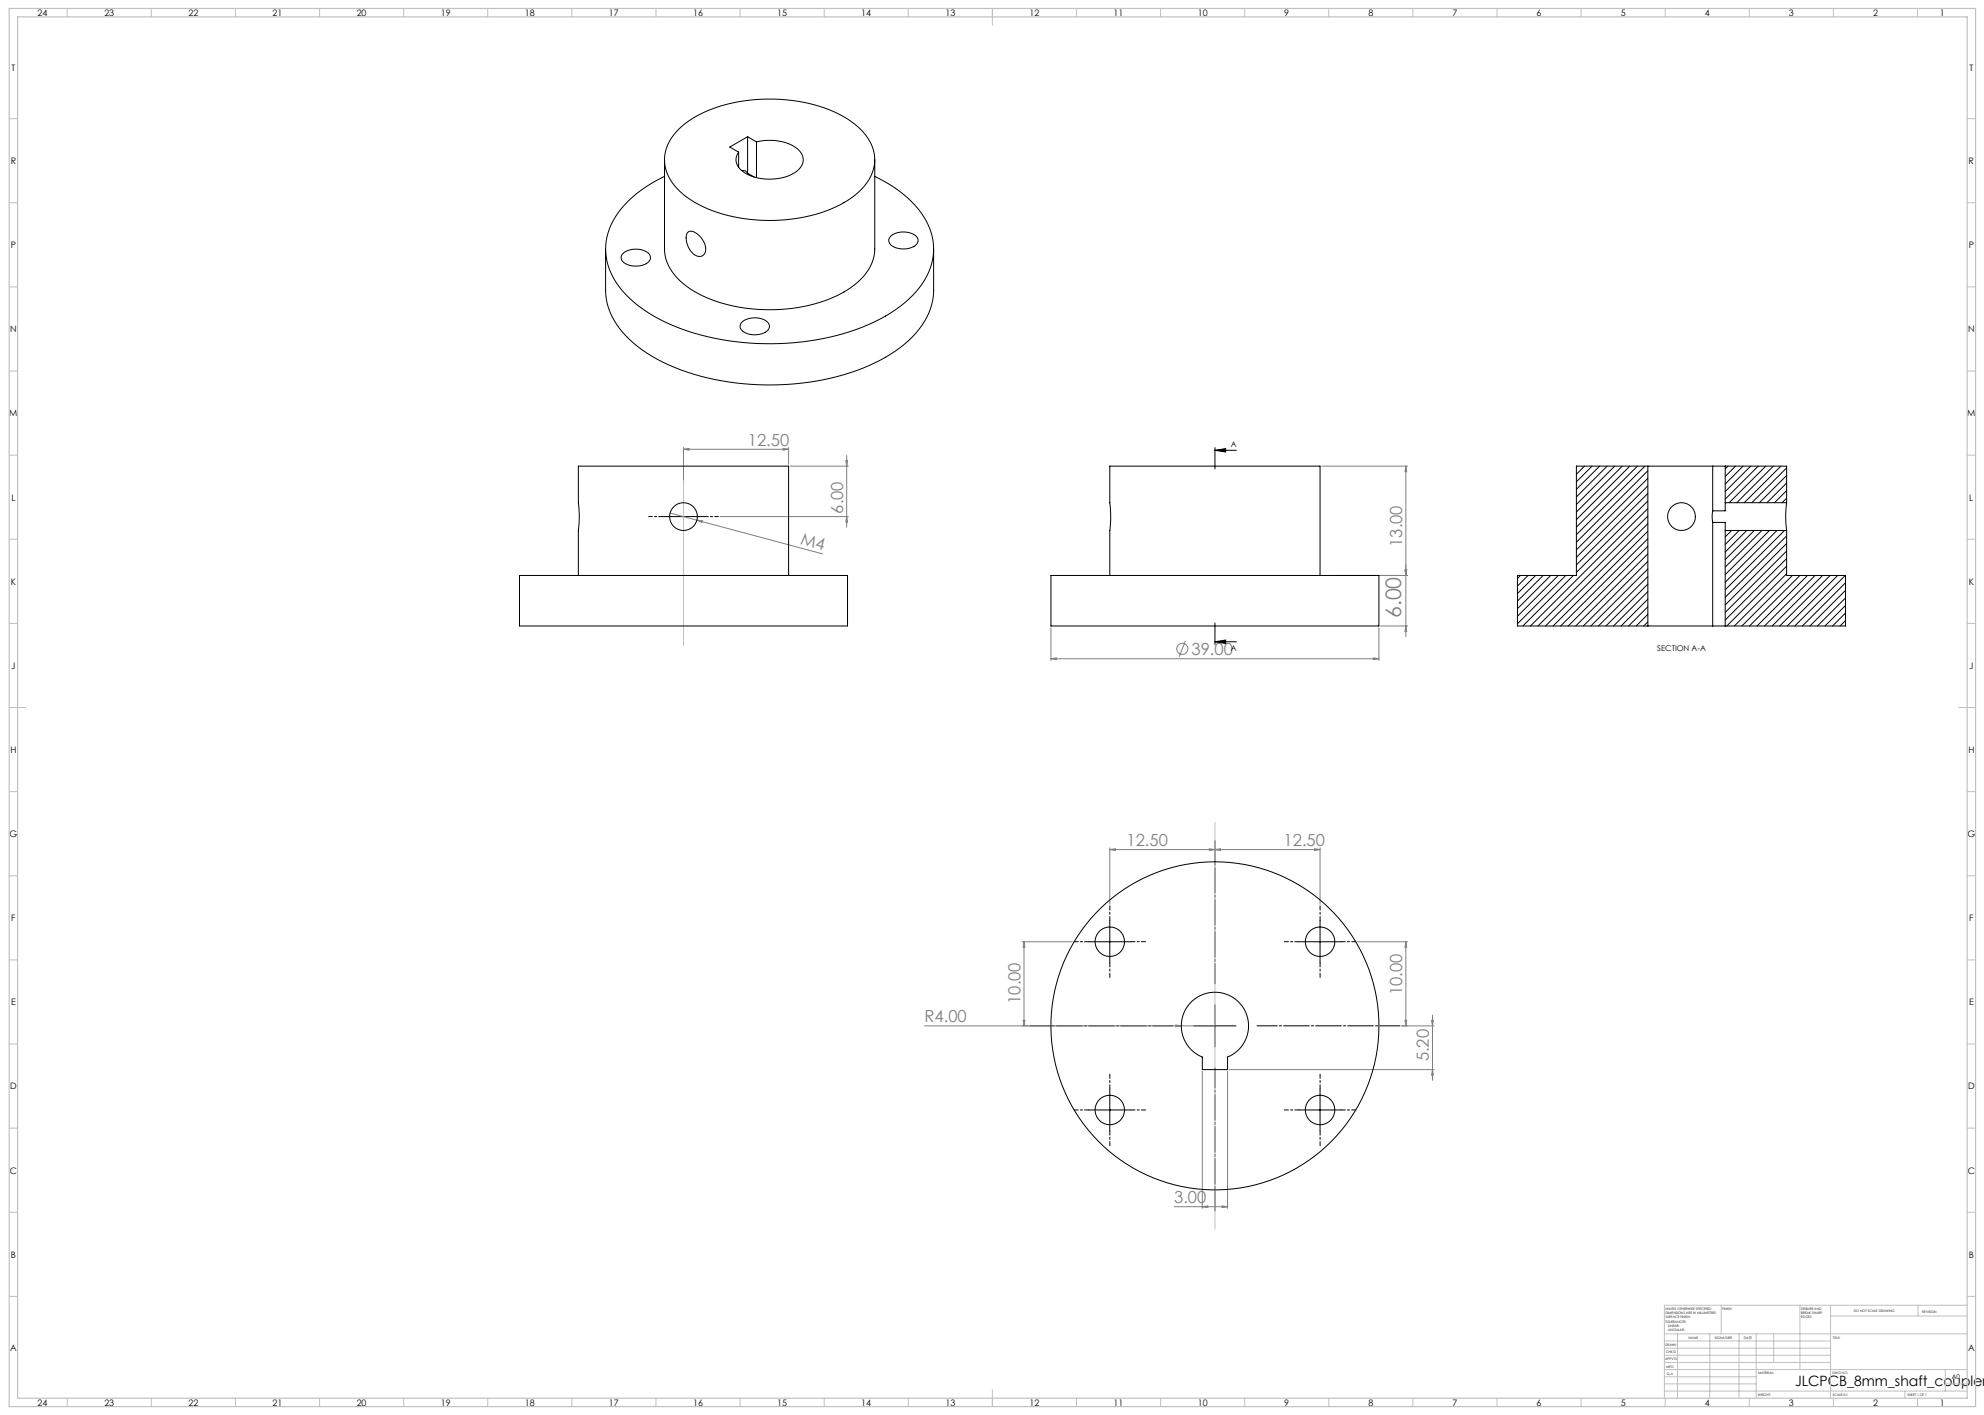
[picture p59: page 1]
SECTION A-A; FINISH:; DEBURR AND; BREAK SHARP; DO NOT SCALE DRAWING; REVISION; SCALE:5:1; SHEET 1 OF 1

UNLESS OTHERWISE SPECIFIED:
DIMENSIONS ARE IN MILLIMETERS
SURFACE FINISH:
TOLERANCES:
LINEAR:
ANGULAR:

NAME | SIGNATURE | DATE | | | | TITLE:

DRAWN
CHK'D
APPV'D
MFG
Q.A | | | | MATERIAL: | DWG NO. | A0

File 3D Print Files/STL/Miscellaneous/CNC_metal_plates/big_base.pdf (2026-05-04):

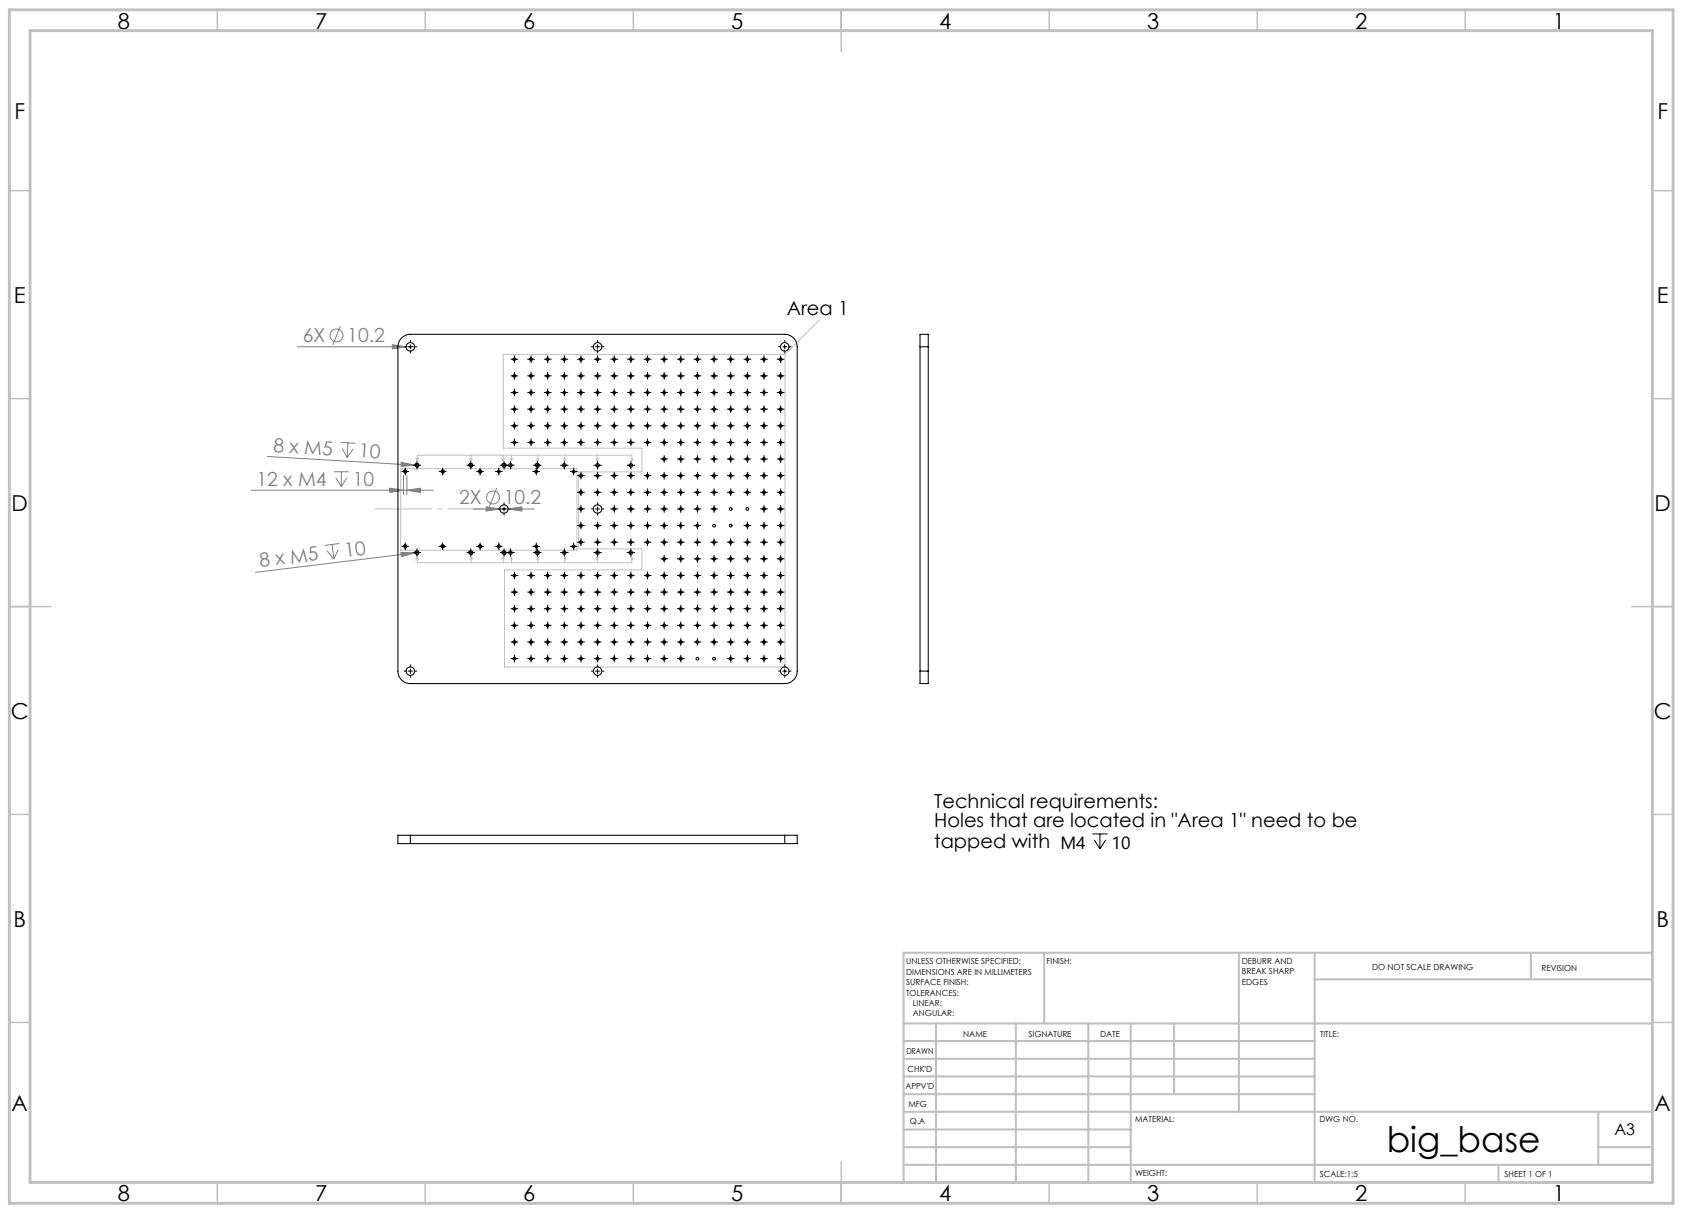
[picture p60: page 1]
Area 1; FINISH:; DEBURR AND; BREAK SHARP; DO NOT SCALE DRAWING; REVISION; SCALE:1:5; SHEET 1 OF 1

Technical requirements:
Holes that are located in "Area 1" need to be
tapped with M4 10

UNLESS OTHERWISE SPECIFIED:
DIMENSIONS ARE IN MILLIMETERS
SURFACE FINISH:
TOLERANCES:
LINEAR:
ANGULAR:

NAME | SIGNATURE | DATE | | | | TITLE:

DRAWN
CHK'D
APPV'D
MFG
Q.A | | | | MATERIAL: | DWG NO. big_base | A3

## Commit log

2026-02-04 BOM update
2026-02-05 Update BOM and images
2026-02-05 update cable assembly file
2026-03-25 stl update
    [42_pulley_old.STL, Base_bearing_backplate.STL, Elbow_blocker.STL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]
2026-04-08 Add multicolor
    [Cable_tie_mount.STL, J5_belt_lid_multicolor.3mf, J5_belt_lid_multicolor.gcode.3mf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]
2026-05-03 Add assembly manual link to README
    Added link to assembly manual video.
2026-05-04 added metal plates
    [big_base.STEP, small_base.STEP]
2026-05-04 Added print table
2026-05-13 Update to print table
2026-05-20 Update J2 Motor holder
    [J2_turret_motor_holder.STL]
2026-06-17 Enhance README with assembly video links
    Added video links for cable assembly and RCB box.
2026-06-26 Update turret & Machined parts
    [8mm_shaft_coupler_Keyway.SLDDRW, 8mm_shaft_coupler_Keyway.SLDPRT, 8mm_shaft_coupler_Keyway.STEP]
2026-06-26 BOM updates
2026-06-26 Another BOM update
2026-06-26 Update cables
2026-06-27 Update cable building
2026-06-27 Update BOM & cable assembly
2026-07-12 Quick motor setup
2026-07-29 Added 3mf printing files with single and multicolor options
2026-07-29 Added 3mf printing files for most Prusa printers and edited 2 previous files for wrong arm infill.
2026-08-04 chore(3d-print): deleted old 3mf files and recreated everything using one file per plate.
    [Plate 1.3mf, Plate 2.3mf, Plate 3.3mf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]
2026-08-17 Add extension wire to BOM and add PAROL6 to PAR6 comparison workbook
    Wires / Cables: add loose wire for building and extending the XH and ZH
    cables (5m black + 5m red per family; 22 or 24 AWG for XH power, 28 AWG
    for ZH CAN), as discussed on Discord.
    BOM/PAROL6 to PAR6 BOM.xlsx: comparison workbook with the PAROL6, PAR6
    arm and RCB BOMs (all purchase links included), a part by part
    comparison of what carries over from a PAROL6, and a rough cost
    estimate. Compiled from the upstream BOMs as of 2026-08-17.
    [PAROL6 to PAR6 BOM.xlsx]
2026-09-27 Update STL files
    [J2_blocker.STL, J5_part.STL, Turret.STL]
2026-10-31 Pin the cross-platform reproducible description build
2026-11-01 Add PAR6 guide links for MSG built-in camera previews
2026-11-03 Pin guide links to the final validated MoveIt source
2026-11-04 CITATION.cff: GitHub's Cite this repository button (Source Robotics, Petar Crnjak)
2026-11-05 BOM: a working link for the thermal cement (the old product page is gone)
2026-11-05 BOM: BOM.md becomes BOM/README.md, so GitHub shows the BOM when the folder opens
2026-11-05 BOM: a short BOM.md that points to README.md, for the older links; links to the folder

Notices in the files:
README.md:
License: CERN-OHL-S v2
